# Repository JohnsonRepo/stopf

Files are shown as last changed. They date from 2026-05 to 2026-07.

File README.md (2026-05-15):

# Zigarettenstopfmaschine

DIY vollautomatische Zigarettenstopfmaschine mit zweischichtiger Architektur:
**Raspberry Pi Zero 2 W** (Brain) + **Arduino Nano** (Echtzeitsteuerung).

## Repo-Struktur

Legende: Dateien ohne Marker existieren; **(geplant)** = noch nicht angelegt.

```
stopfmaschine/
├── CLAUDE.md              # Projekt-Kontext für Claude Code
├── README.md              # Dieses File
├── .gitignore
│
├── firmware/
│   └── nano/              # Arduino Nano Firmware
│       ├── src/
│       │   ├── main.cpp           # Einstiegspunkt (Test-Firmware v0.1)
│       │   ├── pins.h             # Pin-Belegung zentral
│       │   └── config.h           # Konstanten (Speeds, Timeouts)
│       │   # (geplant) commands.*, motors.*, sensors.*, statemachine.*
│       └── platformio.ini
│
├── backend/
│   └── pi/                # Raspberry Pi Brain (Python/FastAPI)
│       ├── app/
│       │   ├── __init__.py
│       │   ├── main.py            # FastAPI Entry + Endpoints
│       │   └── nano_client.py     # Serial-Kommunikation
│       │   # (geplant) api/, models/, db/
│       ├── requirements.txt
│       └── # (geplant) tests/
│
├── cad/                   # CAD-Quellen & Fertigungsdateien
│   ├── README.md          # CAD-Doku & Bauteilübersicht
│   ├── source/            # Master-DXFs (Fraens-Originale)
│   ├── drawings/
│   │   └── acryl_parts/   # Laser-Cut-DXFs (4 mm PMMA)
│   ├── reference/
│   │   └── metal_parts/   # Metallteile-Zeichnungen (DXF + PDF)
│   ├── stl/               # 3D-Druck-Dateien (PETG/PLA)
│   └── scad/              # OpenSCAD-Quellen (Platzhalter)
│
├── docs/                  # Schaltpläne & Referenzen
│   ├── wiring.md          # Schaltpläne (Mermaid + ASCII-Detail)
│   ├── pinout.md          # Pin-/Verdrahtungstabellen + Bestelllisten
│   └── protocol.md        # Serial-Protokoll Pi ↔ Nano
│
└── app/                   # Mobile App (Flutter primär) — (geplant)
```

## Schnellstart

### Arduino Nano (PlatformIO empfohlen)

```bash
cd firmware/nano
pio run                    # Kompilieren
pio run -t upload          # Auf Nano flashen
pio device monitor         # Serial Monitor (115200 Baud)
```

### Raspberry Pi Backend

```bash
cd backend/pi
python -m venv .venv
source .venv/bin/activate
pip install -r requirements.txt
uvicorn app.main:app --host 0.0.0.0 --port 8000 --reload
```

API-Docs anschließend unter `http://<pi-ip>:8000/docs`.

## Test-Reihenfolge

Siehe `CLAUDE.md` Abschnitt "Test-Reihenfolge". Wichtigster Hinweis:
**Buck-Konverter VOR Anschluss auf 5,0V justieren** und **A4988 Vref auf 0,7-1,0V einstellen**.

## Sicherheit

⚠️ Diese Maschine arbeitet mit 12V/5A und beweglichen Teilen.
Notaus-Knopf hardware-seitig einbauen (unterbricht 12V direkt).
Watchdog im Nano-Code stoppt alle Motoren bei Pi-Verbindungsverlust > 5s.

## Lizenz / Hinweis

Eigenbau für privaten Gebrauch. Verkauf der Maschine ist nach §30 TabStG verboten.

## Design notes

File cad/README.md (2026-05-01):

# CAD-Verzeichnis

Alle CAD-Quellen, Zeichnungen, 3D-Druck-Dateien und externe Referenzen für die Zigarettenstopfmaschine.

## Verzeichnisstruktur

```
cad/
├── README.md                     # diese Datei
├── source/                       # Master-DXFs (Fraens-Originale, ungesplittet, für Onshape-Import)
├── reference/                    # Externe Referenzen (Fraens-Vorlagen, Metallteile-Zeichnungen)
│   └── metal_parts/              # Einzel-DXFs + PDFs der Metallteile (Pos.63–87)
├── drawings/                     # Fertigungs-fertige Zeichnungen
│   └── acryl_parts/              # Laser-Cut-DXFs für Acryl-Strukturteile (4 mm)
├── stl/                          # STL-Dateien für 3D-Druck (PETG/PLA)
└── scad/                         # OpenSCAD-Quellen für eigene parametrische Anpassungen (leer)
```

**Hinweis:** Aktuell sind keine `.scad`-Dateien vorhanden. Der Ordner ist als Platzhalter angelegt
(via `.gitkeep`), für künftige eigene OpenSCAD-Konstruktionen (z. B. parametrische Halter,
Stopfrohr-Adapter, Magazin-Aufsätze).

**Hinweis Metallteile:** `reference/metal_parts/` ist als Referenz/Bestellunterlage gedacht — das ist,
was an die CNC-/Edelstahl-Werkstatt geht. Falls die Metallteile später als reguläre Eigenfertigung
gelten sollen, kann der Ordner zu `drawings/metal_parts/` verschoben werden.

## Materialien & Fertigungsverfahren

| Kürzel | Bedeutung |
|---|---|
| **PMMA GS 4 mm** | Acrylglas, gegossen, 4 mm Stärke (NICHT extrudiert) — Strukturteile |
| **Edelstahl V2A** | rostfreier Stahl, CNC- oder Laser-geschnitten — Tragteile, Wellen |
| **PETG / PLA** | 3D-Druck-Filament — Halter, Führungen, nicht-tragend |
| **Lasern** | DXF an Laser-Schnitt-Dienstleister (kunststoffplattenonline.de o. ä.) |
| **CNC** | Frästeil oder Edelstahl-Wasserstrahl/Laser |
| **3D-Druck** | Drucken in PETG (mechanische Teile) oder PLA (Prototyp) |

## Bauteilübersicht

| Name | Datei | Material | Fertigung | Status |
|---|---|---|---|---|
| **Acryl-Strukturteile (Master)** | [`source/Acryl cuttings_01.DXF`](source/Acryl%20cuttings_01.DXF) | PMMA GS 4 mm | Lasern | ✅ Master vorhanden |
| **Stopfmaschine Gesamt-Layout** | [`source/Stuffing machine_00.DXF`](source/Stuffing%20machine_00.DXF) | – | Referenz | ✅ |
| **Metallteile-Übersicht (Master)** | [`source/Metal parts.DXF`](source/Metal%20parts.DXF) | Edelstahl V2A / Stahl | CNC / Laser | ✅ Master vorhanden |
| **Grundplatte Pos.75** | [`source/Base plate Pos-75.DXF`](source/Base%20plate%20Pos-75.DXF) | PMMA GS 4 mm | Lasern | ✅ |
| Acryl-Teil Pos.95 | [`drawings/acryl_parts/acryl_teil1.dxf`](drawings/acryl_parts/acryl_teil1.dxf) | PMMA GS 4 mm | Lasern | 🔲 zu bestellen |
| Acryl-Teil Pos.96 | [`drawings/acryl_parts/acryl_teil2.dxf`](drawings/acryl_parts/acryl_teil2.dxf) | PMMA GS 4 mm | Lasern | 🔲 zu bestellen |
| Acryl-Teil Pos.97 | [`drawings/acryl_parts/acryl_teil3.dxf`](drawings/acryl_parts/acryl_teil3.dxf) | PMMA GS 4 mm | Lasern | 🔲 zu bestellen |
| Acryl-Teil Pos.98 | [`drawings/acryl_parts/acryl_teil4.dxf`](drawings/acryl_parts/acryl_teil4.dxf) | PMMA GS 4 mm | Lasern | 🔲 zu bestellen |
| Acryl-Teil Pos.99 | [`drawings/acryl_parts/acryl_teil5.dxf`](drawings/acryl_parts/acryl_teil5.dxf) | PMMA GS 4 mm | Lasern | 🔲 zu bestellen |
| Acryl-Teil Pos.100 | [`drawings/acryl_parts/acryl_teil6.dxf`](drawings/acryl_parts/acryl_teil6.dxf) | PMMA GS 4 mm | Lasern | 🔲 zu bestellen |
| Acryl-Teil Pos.101 | [`drawings/acryl_parts/acryl_teil7.dxf`](drawings/acryl_parts/acryl_teil7.dxf) | PMMA GS 4 mm | Lasern | 🔲 zu bestellen |
| Acryl-Teil Pos.102 | [`drawings/acryl_parts/acryl_teil8.dxf`](drawings/acryl_parts/acryl_teil8.dxf) | PMMA GS 4 mm | Lasern | 🔲 zu bestellen |
| Acryl-Teil Pos.103 | [`drawings/acryl_parts/acryl_teil9.dxf`](drawings/acryl_parts/acryl_teil9.dxf) | PMMA GS 4 mm | Lasern | 🔲 zu bestellen |
| Acryl-Teil Pos.104 | [`drawings/acryl_parts/acryl_teil10.dxf`](drawings/acryl_parts/acryl_teil10.dxf) | PMMA GS 4 mm | Lasern | 🔲 zu bestellen |
| Acryl-Teil Pos.105 | [`drawings/acryl_parts/acryl_teil11.dxf`](drawings/acryl_parts/acryl_teil11.dxf) | PMMA GS 4 mm | Lasern | 🔲 zu bestellen |
| Acryl-Teil Pos.106 | [`drawings/acryl_parts/acryl_teil12.dxf`](drawings/acryl_parts/acryl_teil12.dxf) | PMMA GS 4 mm | Lasern | 🔲 zu bestellen |
| Acryl-Teil Pos.107 | [`drawings/acryl_parts/acryl_teil13.dxf`](drawings/acryl_parts/acryl_teil13.dxf) | PMMA GS 4 mm | Lasern | 🔲 zu bestellen |
| Acryl-Teil Pos.108 | [`drawings/acryl_parts/acryl_teil14.dxf`](drawings/acryl_parts/acryl_teil14.dxf) | PMMA GS 4 mm | Lasern | 🔲 zu bestellen |
| Acryl-Sammelblatt 1 | [`drawings/acryl_parts/acryl1.dxf`](drawings/acryl_parts/acryl1.dxf) | PMMA GS 4 mm | Lasern | ✅ alternative Bestellvorlage |
| Acryl-Sammelblatt 2 | [`drawings/acryl_parts/acryl2.dxf`](drawings/acryl_parts/acryl2.dxf) | PMMA GS 4 mm | Lasern | ✅ alternative Bestellvorlage |
| Metallteile Pos.63–87 (split) | [`reference/metal_parts/`](reference/metal_parts/) | Edelstahl V2A / Stahl | CNC / Laser | 🔲 Werkstatt-Anfrage offen |
| 3D-Druck-Teile (alle) | [`stl/`](stl/) | PETG / PLA | 3D-Druck | 🔄 teilweise gedruckt |

### Status-Legende

- ✅ vorhanden / fertig / verfügbar
- 🔄 in Arbeit / teilweise erledigt
- 🔲 offen / noch zu erledigen
- ❌ verworfen / nicht relevant

## Workflow

1. **Onshape-Anpassungen** → eigene Änderungen parametrisch (Variables für Kernmaße, siehe `CLAUDE.md`).
2. **Export** → DXF in `source/` (Master) bzw. `drawings/acryl_parts/` (Fertigungsstand).
3. **Lasern** → DXF aus `drawings/acryl_parts/` an Dienstleister
   (kunststoffplattenonline.de, S-Polytec.de, Acrylglasplattenshop.de, Plattenzuschnitt24.de).
4. **3D-Druck** → STL aus `stl/` in den Slicer; Empfehlung PETG für mechanische Teile.
5. **Metallteile** → DXF + PDF aus `reference/metal_parts/` an die Edelstahl-Werkstatt.

## Reihenfolge der Eigen-Konstruktion (laut CLAUDE.md)

1. Stopfrohr-Halter + Pusher-Führung
2. Trommelmagazin
3. Tabakmagazin / Gehäuse

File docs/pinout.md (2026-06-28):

# Pinout & Verdrahtungstabelle

Vollständige Belegung aller Pins mit Kabelfarben und Zielbauteil.
Quelle der Pin-Nummern: [`firmware/nano/src/pins.h`](../firmware/nano/src/pins.h).

---

## Arduino Nano (final)

### Digitale Pins

| Pin | `pins.h`-Konstante | Funktion | Ziel | Kabelfarbe (Vorschlag) | Anmerkung |
|---|---|---|---|---|---|
| D2 | `PIN_STEPPER_STEP` | Step-Impuls | A4988 STEP | gelb | jeder steigende Flanke = 1 Step |
| D3 | `PIN_STEPPER_DIR` | Richtung | A4988 DIR | grün | HIGH/LOW = Drehrichtung |
| D4 | `PIN_STEPPER_EN` | Enable | A4988 EN | weiß | **LOW = Treiber aktiv** (invertiert!) |
| D5 | `PIN_PRESS_ENA` | Presse Drehzahl | L298N ENA | gelb | **PWM** Timer0 (Servo-unabhängig) |
| D6 | `PIN_PUSHER_ENB` | Pusher Drehzahl | L298N ENB | grün | **PWM** Timer0 (Servo-unabhängig) |
| D7 | `PIN_PRESS_IN1` | Presse Richtung A | L298N IN1 | orange | digital |
| D8 | `PIN_PRESS_IN2` | Presse Richtung B | L298N IN2 | rot | digital |
| D9 | `PIN_PUSHER_IN3` | Pusher Richtung A | L298N IN3 | violett | digital (Servo killt hier nur PWM) |
| D10 | `PIN_PUSHER_IN4` | Pusher Richtung B | L298N IN4 | blau | digital |
| D11 | `PIN_SERVO` | Servo-Signal Hülsen-Schieber | SG90 (orange Litze) | orange | **PWM** (Servo-Library) |
| D12 | `PIN_HOPPER_MOTOR` | Hülsenmagazin-Motor | MOSFET-Gate (2N7000 / IRLZ44N) | grau | digital ON/OFF (5 V, ~40 mA Last) |
| D13 | `PIN_SOLENOID_2` | Hubmagnet #2 (Top-Druck) | MOSFET-Gate (IRLZ44N) | weiß | digital ON/OFF, Heschen HS-0530B (12 V) |

### Analoge Pins (nutzbar als digital, hier teils analog)

| Pin | `pins.h`-Konstante | Funktion | Ziel | Verdrahtung | Anmerkung |
|---|---|---|---|---|---|
| A0 | `PIN_INIT_PRESS` | Initiator Press | LJ8A3-2-Z/BX (schwarz) | über 10 k + 7,5 k Spannungsteiler | active LOW |
| A1 | `PIN_INIT_PUSH_FRONT` | Initiator Pusher vorne | LJ8A3-2-Z/BX (schwarz) | über 10 k + 7,5 k | active LOW |
| A2 | `PIN_INIT_PUSH_REAR` | Initiator Pusher hinten | LJ8A3-2-Z/BX (schwarz) | über 10 k + 7,5 k | active LOW |
| A3 | – | **frei** (Reserve) | – | – | z. B. zukünftige Sensoren oder I²C-Display |
| A4 | `PIN_SOLENOID_1` | Hubmagnet #1 (Front-Knock) | MOSFET-Gate (IRLZ44N) | digital ON/OFF, Heschen HS-0530B (12 V) |
| A5 | `PIN_MAGAZIN_SENSOR` | Magazin-Gabellichtschranke | Oniissy / Standard-Opto | direkt 5 V-Logik, kein Spannungsteiler |

### Versorgungs-Pins

| Pin | Verbindung | Anmerkung |
|---|---|---|
| **VIN** | – nicht verwenden | Nano wird über USB vom Pi versorgt |
| **5V** | optional kleine Verbraucher (Start-Taster braucht NICHT, Buck-Out hat eigene 5 V) | max. 500 mA aus dem Nano-Regler |
| **3V3** | – nicht verwenden | für 3,3 V-Sensoren reserviert |
| **GND** (mehrfach) | **Sternpunkt am Netzteil** | 1× direkt zum Power-GND, 1× zum Pi |

---

## L298N Standard-Modul (Doppel-DC-Motortreiber, mit Kühlkörper)

> Großes Modul mit Schraubklemmen und ENA/ENB. Drehzahl-Regelung über separate
> Enable-Pins, funktioniert in **beide** Richtungen.

| L298N-Pin | Verbindung | Anmerkung |
|---|---|---|
| V_S (12 V) | 12 V Netzteil + 470 µF Elko (**Schraubklemme**) | Motor-Versorgung |
| GND | GND-Sternpunkt (**Schraubklemme**) | |
| +5 V | – nicht abgreifen für Pi/Servo | Jumper "5V_EN" stecken lassen wenn V_S = 12 V |
| ENA | Nano **D5 (PWM)** | Presse Drehzahl — Timer0, Servo-unabhängig |
| ENB | Nano **D6 (PWM)** | Pusher Drehzahl — Timer0, Servo-unabhängig |
| IN1 | Nano D7 | Presse Richtung A |
| IN2 | Nano D8 | Presse Richtung B |
| IN3 | Nano D9 | Pusher Richtung A |
| IN4 | Nano D10 | Pusher Richtung B |
| OUT1/OUT2 | DC-Motor Presse (**Schraubklemme**) | Polarität egal, ggf. tauschen für Drehrichtung |
| OUT3/OUT4 | DC-Motor Pusher (**Schraubklemme**) | dito |

> ⚠️ **Timer-Konflikt beachten:** `Servo.h` belegt auf dem ATmega328 Timer1 und
> deaktiviert PWM auf D9/D10. ENA/ENB **müssen** deshalb auf D5/D6 (Timer0).
> Die IN-Pins sind reine Richtungs-Logik → D7–D10 unproblematisch (digital).

### Wahrheitstabelle

| INx | INy | ENx (PWM) | Verhalten |
|---|---|---|---|
| HIGH | LOW | > 0 | Motor vorwärts (`fwd`) mit Drehzahl |
| LOW | HIGH | > 0 | Motor rückwärts (`rev`) mit Drehzahl |
| LOW | LOW | beliebig | Motor frei (Coast) |
| HIGH | HIGH | beliebig | Motor gebremst (Brake) |
| beliebig | beliebig | 0 | Motor aus (PWM-Stop) |

> **Vorteil ggü. Mini-Modul:** echte Drehzahl-Regelung in beide Richtungen,
> dicke Litze passt in die Schraubklemmen, Coast (Freilauf) möglich,
> besserer Kühlkörper.

---

## A4988 Schrittmotor-Treiber

| A4988-Pin | Verbindung | Anmerkung |
|---|---|---|
| V_MOT | 12 V + 100 µF Elko | **Pflicht!** Elko < 5 cm vom IC |
| GND (Motor) | GND-Sternpunkt | |
| V_DD | 5 V (vom Nano oder Buck) | Logik-Versorgung |
| GND (Logik) | GND-Sternpunkt | |
| STEP | Nano D2 | |
| DIR | Nano D3 | |
| EN | Nano D4 | LOW = aktiv |
| RESET | mit SLEEP brücken | beide HIGH = Treiber an |
| SLEEP | mit RESET brücken | |
| MS1/MS2/MS3 | offen lassen | Vollschritt; für Microstepping nach Bedarf |
| 1A / 1B | NEMA 17 Spule A | (meist schwarz/grün) |
| 2A / 2B | NEMA 17 Spule B | (meist rot/blau) |
| **Vref-Poti** | mit Multimeter messen | **0,7 ... 1,0 V** vor erstem Anlauf |

---

## NEMA 17 Schrittmotor

Standard-Belegung (variiert pro Hersteller — mit Multimeter durchklingeln!):

| Litzenfarbe (typisch) | Spule | Anschluss |
|---|---|---|
| schwarz | A | A4988 1A |
| grün | A | A4988 1B |
| rot | B | A4988 2A |
| blau | B | A4988 2B |

---

## SG90 Servo (Hülsen-Schieber — einziger Servo)

Im finalen Aufbau gibt es **nur einen Servo** (für das Aufschieben der Hülse).
Die Tabak-Dosierung läuft komplett über 2 Solenoide ohne Servo.

| Litzenfarbe | Funktion | Anschluss |
|---|---|---|
| rot | VCC 5 V | Buck-Out + 470 µF Elko lokal am Servo |
| braun / schwarz | GND | GND-Sternpunkt |
| orange / gelb | Signal (PWM) | Nano **D11** |

---

## Hubmagnete Heschen HS-0530B (2 Stück, Tabak-Dosierung)

12V Push/Pull-Solenoid, ~5 mm Hub, ~3–5 N Zugkraft, ~0,5 A nominal (Halte­strom
bei aktivem Coil ~1 A), ~14×30 mm. Intermittierender Betrieb (kurze Pulse
50–150 ms), nicht für Dauer-ON ausgelegt.

| Litze | Funktion | Anschluss |
|---|---|---|
| Solenoid #1 (Front-Knock) | beide Anschlüsse | über MOSFET-Treiber an Nano A4 |
| Solenoid #2 (Top-Druck) | beide Anschlüsse | über MOSFET-Treiber an Nano D13 |

Steuerung pro Solenoid via **Logic-Level-MOSFET** (z. B. IRLZ44N):

| Bauteil | Anschluss |
|---|---|
| Solenoid + | 12 V-Bus (über F4 = 1 A T) |
| Solenoid − | Drain des MOSFETs |
| 1N5819 Flyback | Kathode an +12 V, Anode an Drain (parallel zum Solenoid) |
| MOSFET Source | GND-Sternpunkt |
| MOSFET Gate | über 100 Ω Series an Nano-Pin (A4 oder D13) |

> **Warum nicht L298N-Mini?** Wäre theoretisch ein 2-Kanal-Treiber für beide
> Solenoide. **Aber:** Halte­strom 1 A × 2,5 V L298N-Drop = 2,5 W pro Kanal,
> bei beiden aktiv 5 W → das Mini-Modul ohne Kühlkörper überhitzt. MOSFET hat
> < 20 mV Drop → kalt.

> **Polung Solenoid:** DC-Solenoide haben keine elektrische Polarität, aber
> konsistente Anschluss-Konvention vereinfacht Wartung.

> **Flyback-Diode Pflicht** (nicht optional wie bei L298N) — beim Abschalten
> erzeugt die Solenoid-Spule eine hohe Back-EMF-Spitze, die den MOSFET ohne
> Schutz beschädigt.

---

## Hülsenmagazin-Motor (1 Stück, 5 V Vibrationsmotor)

Kleiner DC-Motor zum Vorrücken/Rütteln der Hülsen im Magazin. ~40 mA bei 5 V,
nur on/off (Drehzahl-Regelung nicht nötig).

| Bauteil | Anschluss |
|---|---|
| Motor + | 5 V-Bus (vom Buck-Out, nicht vom Nano-5V-Pin) |
| Motor − | Drain des MOSFETs |
| 1N4148 Flyback | Kathode an +5 V, Anode an Drain (parallel zum Motor) |
| MOSFET Source | GND-Sternpunkt |
| MOSFET Gate | über 1 kΩ Series an Nano D12 |

> **MOSFET-Wahl:** 2N7000 (TO-92, ~10 ct) ist optimal für 40 mA. IRLZ44N geht
> auch (overkill aber konsistent mit Solenoid-Treibern).

> **Warum 1N4148 statt 1N5819?** Bei 40 mA reicht die 200 mA-Dauerlast-
> Spec der 1N4148 dicke. 1N5819 wäre overkill und die hast du eh für die
> Solenoide.

> **Nicht direkt vom Nano-Pin treiben:** Nano-Pin verträgt max 40 mA — exakt am
> Limit, plus Anlaufspitze + Back-EMF → Pin-Schutzdiode wird über Zeit stressed.
> MOSFET ist die sichere Lösung.

---

## Start-Taster — entfällt

Manueller Hardware-Start ist nicht vorgesehen. Die Maschine wird **komplett
remote** über den Raspberry Pi gesteuert (HTTP-API, später BLE). Pin D12 ist
für den Hülsenmagazin-Motor umgewidmet.

---

## Initiatoren LJ8A3-2-Z/BX oder LJ12A3-4-Z/BX (3 Stück)

| Litzenfarbe | Funktion | Anschluss |
|---|---|---|
| braun | +12 V | 12 V Bus |
| blau | GND | GND-Sternpunkt |
| schwarz | Signal (NPN, 12 V active LOW) | Spannungsteiler 10 k + 7,5 k → A0 / A1 / A2 |

> **LJ8 vs. LJ12:** elektrisch identisch (NPN, active LOW, gleicher Spannungsteiler,
> gleicher Code). Unterschied nur mechanisch: LJ8 = M8/2 mm Schaltabstand,
> LJ12 = M12/4 mm (größere Bohrung, Target ≥ 12×12 mm). Beide verwendbar.

---

## Raspberry Pi Zero 2 W (Brain)

| Pi-Pin | Funktion | Anschluss |
|---|---|---|
| Pin 2 (5 V) | Versorgung **rein** | Buck-Out 5 V (≥ 3 A) |
| Pin 6 (GND) | GND | GND-Sternpunkt |
| – | USB-A oder Micro-USB-OTG | → Arduino Nano (Daten + 5 V Versorgung des Nano) |
| Pin 8 (TX) / Pin 10 (RX) | optional: UART zum Nano | falls USB nicht genutzt — mit Pegelwandler! |

> **Pi NICHT über Micro-USB-Power speisen** (Polyfuse begrenzt → Brownout unter Last).
> 5 V immer über GPIO Pin 2 einspeisen, Buck vorher auf 5,0 V justieren.

---

## ESP-WROOM-32 (Übergangslösung, parallel dokumentiert)

> Solange der Buck-Konverter noch nicht da ist, kann ein ESP32 als Single-Board-
> Controller alle Funktionen übernehmen. Pin-Mapping ist bewusst anders, weil
> manche ESP32-Pins Boot-Strapping-Pins oder input-only sind.

| Funktion | ESP32 GPIO | Anmerkung |
|---|---|---|
| A4988 STEP | GPIO 25 | |
| A4988 DIR | GPIO 26 | |
| A4988 EN | GPIO 27 | |
| L298N IN1 | GPIO 14 | |
| L298N IN2 | GPIO 12 | ⚠️ Boot-Strapping |
| L298N IN3 | GPIO 13 | |
| L298N IN4 | GPIO 32 | |
| L298N ENA | GPIO 33 | PWM |
| L298N ENB | GPIO 4 | PWM |
| Servo | GPIO 19 | PWM (LEDC-Kanal) |
| (Start-Taster) | – | **entfällt — Steuerung remote über Pi** |
| Initiator Press | GPIO 34 | ⚠️ input-only, kein Pull-Up |
| Initiator PushFront | GPIO 35 | ⚠️ input-only |
| Initiator PushRear | GPIO 36 | ⚠️ input-only |
| Magazin-Sensor | GPIO 39 | ⚠️ input-only |

⚠️ **Spannungsteiler für ESP32:** 10 kΩ + **3,9 kΩ** (nicht 7,5 kΩ wie beim Nano).
   U_out = 12 V · 3,9/13,9 ≈ 3,37 V — innerhalb 3,3 V-Toleranz.

⚠️ **Boot-Strapping-Pins** (GPIO 0, 2, 5, 12, 15) nur mit Bedacht nutzen — falsche
   Pegel beim Reset verhindern den Boot.

---

## Elektrolytkondensatoren (Bestellliste)

Zentrale Pufferkondensatoren — alle 105 °C, radial THT.

| Position | Kapazität | Spannung | Typ | Anzahl | Begründung |
|---|---|---|---|---|---|
| **A4988 V_MOT** | ≥ 100 µF (220 µF besser) | **≥ 25 V** | **Low ESR** Pflicht | 1× | Schaltet 500 kHz, Standard-Elkos zu lahm |
| **L298N V_S** | ≥ 470 µF (1000 µF besser) | **≥ 25 V** | Standard reicht | 1× | DC-Motor-Anlaufstrom puffern |
| **Servo VCC** | ≥ 470 µF (bis 2200 µF) | ≥ 10 V (16 V/25 V auch ok) | Standard | 1× | Servo-Anlaufstrom 0,5–1 A |
| **Buck-Ausgang Bulk** (optional) | 470–1000 µF | ≥ 10 V | Standard | 1× | nur falls Pi und Servo räumlich weit auseinander |

> ⚠️ **Niemals 16 V-Elkos im 12 V-Pfad!** Headroom 33 % ist zu knapp gegen
> Spannungsspikes von Motoren — Elko explodiert, Treiber stirbt mit. Mindestens
> 25 V im 12 V-Pfad. Im 5 V-Pfad sind 10 V/16 V/25 V alle okay (alle ≥ 2× U_op).

### Konkret zum Bestellen

| Bauteil | Quelle | Preis |
|---|---|---|
| Panasonic FC 100 µF/35 V (low ESR) | Reichelt: "FC 100/35" | ~0,40 € |
| Panasonic FC 470 µF/35 V (low ESR) | Reichelt: "FC 470/35" | ~0,80 € |
| Standard 470 µF/25 V/105 °C | Reichelt: "RAD 470/25" | ~0,30 € |
| Standard 1000 µF/35 V/105 °C | Reichelt: "RAD 1000/35" | ~0,80 € |

### Optionale Schutzbauteile

| Bauteil | Wert | Anzahl | Position |
|---|---|---|---|
| Schottky-Flyback-Diode | 1N5819 (1 A, 40 V) | 8× (DC-Motoren) + 2× (Solenoide) | 4 pro DC-Motor an L298N-Ausgängen; 2 für die Heschen-Solenoide (Pflicht!) |

### MOSFET-Treiber (Pflicht für Tabak-Solenoide + Hülsenmagazin-Motor)

| Bauteil | Wert | Anzahl | Position |
|---|---|---|---|
| **MOSFET Logic-Level** | IRLZ44N (TO-220, 30A, ~17 mΩ Rds_on) | 3× | je 1 pro Solenoid + 1 für Hopper-Motor (overkill ok) |
| Alternativ Hopper-Motor | 2N7000 oder BS170 (TO-92, klein) | 1× statt IRLZ44N | nur 40 mA — kleiner ist genug |
| Flyback-Diode Hopper | **1N4148** (200 mA, 100 V) | 1× | parallel zum 40-mA-Motor (1N5819 wäre overkill) |
| Gate-Series-Widerstand | 100 Ω (Solenoide) / 1 kΩ (Hopper) | 3× | dämpft Gate-Switching |

Kosten gesamt: ~1,50 € (3× IRLZ44N + 2× 1N5819 + 1× 1N4148 + 3× R).

---

## Litze / Kabel (Bestellliste)

### Querschnitt pro Strecke

| Strecke | Strom (peak) | Querschnitt | AWG | Farbe |
|---|---|---|---|---|
| **PSU 12 V → F1 → Verteiler** | bis 5 A | **1,0 mm²** | AWG 17 | rot |
| **PSU GND → Sternpunkt** | bis 5 A | **1,0 mm²** | AWG 17 | schwarz |
| 12 V → L298N V_S | 3 A peak | 0,75 mm² | AWG 18 | rot |
| 12 V → A4988 V_MOT | 1 A peak | 0,5 mm² | AWG 20 | rot |
| 12 V → Buck-Eingang | 1 A | 0,5 mm² | AWG 20 | rot |
| 12 V → Initiatoren (braun) | 50 mA | 0,25 mm² | AWG 24 | braun |
| Buck 5 V → Pi GPIO 2 | 700 mA | 0,5 mm² ⚠️ kurz halten | AWG 20 | gelb/orange |
| Buck 5 V → Servo VCC | 1 A peak | 0,5 mm² ⚠️ kurz halten | AWG 20 | rot (am Servo) |
| Buck 5 V → A4988 V_DD | 50 mA | 0,25 mm² | AWG 24 | gelb |
| **Motor-Leitungen L298N → DC-Motor** | 1,5 A | 0,5–0,75 mm² | AWG 18–20 | blau / weiß |
| **NEMA 17 → A4988 (4-adrig)** | 1 A pro Phase | 0,5 mm² je Ader | AWG 20 | schwarz/grün/rot/blau |
| Logik-Signale (STEP, DIR, EN, IN1–4) | < 50 mA | 0,14–0,25 mm² | AWG 26–24 | beliebig |
| Servo-Signal (PWM von Nano) | < 20 mA | 0,14 mm² | AWG 26 | orange |
| MOSFET-Gate-Leitungen (Nano → Gate, mit 100Ω/1kΩ Series) | < 1 mA | 0,14 mm² | AWG 26 | grau |
| Initiator-Signal (schwarz) | < 20 mA | 0,25 mm² | AWG 24 | schwarz/grün |
| GND-Rückleitungen | **wie Hinweg!** | gleicher Querschnitt | – | schwarz |

> ★ **GND-Litze immer mindestens so dick wie die +Leitung.**
> Wer hier spart, bekommt Massepotential-Probleme.

### Spannungsabfall-Überlegung

Faustformel: `U_drop = I · ρ · L / A` mit `ρ_Kupfer = 0,017 Ω·mm²/m`

Toleranz:
- **5 V-Schiene**: max. **100 mV** Drop (sonst Pi-Brownout)
- **12 V-Schiene**: max. **500 mV** Drop (sonst spüren's die Treiber)

Beispiele:
| Pfad | I | L | A | U_drop |
|---|---|---|---|---|
| PSU → Verteiler | 5 A | 0,3 m | 1,0 mm² | 25 mV ✅ |
| PSU → Verteiler | 5 A | 0,3 m | 0,5 mm² | 51 mV ⚠️ |
| Buck → Pi | 0,7 A | 0,5 m | 0,5 mm² | 12 mV ✅ |
| Buck → Pi | 0,7 A | 1,0 m | 0,25 mm² | 48 mV ⚠️ |

### Litze vs. Massivdraht

| | **Litze** (stranded) | Massivdraht (solid) |
|---|---|---|
| Mechanik | flexibel, vibrationsfest | bricht bei wiederholtem Biegen |
| WAGO 221 | ✅ direkt | ✅ direkt |
| Schraubklemme | nur mit **Aderendhülse** | ohne Hülse |
| Empfehlung Stopfmaschine | ✅ **Litze** wegen Vibrationen | nur für kurze Drahtbrücken |

### Aderendhülsen — wann nötig?

| Klemmen-Typ | Aderendhülse? |
|---|---|
| WAGO 221 (Hebelklemme) | ❌ NICHT nötig |
| Schraubklemme (z. B. an L298N, A4988) | ✅ **PFLICHT** |
| Lüsterklemme | ✅ Pflicht |
| Crimp-Stecker (Dupont, JST) | — wird direkt vercrimpt |
| Federzugklemme (Phoenix) | ❌ direkt |

Aderendhülsen-Set 0,14–2,5 mm² mit Crimpzange: ~15–25 €
(Amazon "Knipex-Set" oder Generic).

### Wenn du nur EINE Litze kaufst

→ **0,5 mm² (AWG 20) ist der universelle DIY-Kompromiss.**
Geht für alle 5 V-Leitungen, Treiber-Versorgungen, Motoren, Sensor-Stromversorgung.
Reicht **nicht** für die Hauptzuleitung PSU → Verteiler (zu hoher Spannungsabfall bei 5 A).

### Konkretes Bestell-Paket

| Querschnitt | Menge | Farben | Quelle |
|---|---|---|---|
| 1,0 mm² | 1 m rot + 1 m schwarz | – | Reichelt: "LIY 1,00 RT/SW" |
| 0,5 mm² | 2–3 m rot + schwarz + 2 andere | rot/schwarz/blau/gelb | "LIY 0,50 …" |
| 0,25 mm² | je 1 m in 4–6 Farben | gemischt | "LIY 0,25 …" |
| **Set-Alternative** | 5 m × 10 Farben × 0,25 mm² | gemischt | Amazon: "Litze Sortiment 24 AWG 10 Farben" ~12 € |

**Gesamtbudget für komplette Verkabelung: ~15–25 €**

---

## Spannungsteiler für Initiatoren (Bestellliste)

Pro Sensor-Eingang (3× für Press / PushFront / PushRear):

| Bauteil | Wert | Anzahl | Bauform | Anmerkung |
|---|---|---|---|---|
| R1 | 10 kΩ, 5 %, 1/4 W | 3× (+ Reserve) | THT 0207 | Standard-Kohleschicht |
| R2 (Nano) | 7,5 kΩ, 5 %, 1/4 W | 3× | THT 0207 | für 5 V-Logik (Standard) |
| R2 Ersatz #1 | **6,8 kΩ** statt 7,5 kΩ | 3× | THT 0207 | häufiger lagernd, U_out 4,86 V |
| R2 Ersatz #2 | **5,6 kΩ + 2 kΩ in Reihe** | je 3× | THT 0207 | falls 7,5/6,8 fehlen — Reihe addiert zu 7,6 kΩ |
| R2 (ESP32) | 3,9 kΩ, 5 %, 1/4 W | 3× | THT 0207 | für 3,3 V-Logik |
| C (Filter) | 47 nF Keramik | 3× | X7R, 50 V | parallel zu R2, EMV-Filter |

Optionale Pull-up-Bestückung **falls** der Sensor im Leerlauf < 10 V auf Schwarz zeigt:

| Bauteil | Wert | Anzahl | Anmerkung |
|---|---|---|---|
| R_pullup | 4,7 kΩ, 1/4 W | 3× | von "schwarz" nach +12 V, **nur wenn nötig** |

> Vor dem Anschluss am Nano: Test-Checkliste in [`wiring.md` § 3](wiring.md#3-initiator-spannungsteiler-kritisch) durchgehen.

---

## Sicherungen (Bestellliste)

Alle 5×20 mm Schmelzsicherungen (Glas oder Keramik beide ok), in Schraubklemmen-Halter
(z. B. Stelvio Kontek PTF/30 oder beliebiger Würth/Schurter-Halter).

| Position | Wert | Charakteristik | Schützt | Halter-Typ |
|---|---|---|---|---|
| **F1** Hauptsicherung 12 V | 5 A | T (träge) | gesamten 12 V-Bus, Verkabelung | Schraubklemme, Panel-mount |
| **F2** Buck-Eingang | 1 A | T (träge) | Pi + Servo + Nano-Logik | Schraubklemme, inline |
| **F3** Initiator-Schiene | 500 mA | F (flink) | Sensor-Verkabelung | Schraubklemme, inline |

> **Glas oder Keramik — beides ok für 12 V DC.** Beide elektrisch identisch
> (gleicher Wert, gleiche Charakteristik T/F). Glas ist günstiger (~0,30 € vs.
> ~1–2 €), Keramik hat mehr Headroom bei Hochstrom-Fehlern. Für diese Maschine
> Wahl-Sache. Keramik **wird** Pflicht bei AC-Netzseite (vor dem 12 V-Netzteil)
> oder Bleibatterie/LiPo-Versorgung > 100 A Kurzschluss. Details in
> [`wiring.md` § 1](wiring.md#1-stromversorgung-power-distribution).

> **Reserve mitbestellen:** je Wert mind. 5 Stück, sind günstig (~0,30 €/Stück).

---

## GND-Sternpunkt (★ kritisch ★)

Alle GNDs an **einem Punkt** zusammenführen, am besten direkt an der GND-Klemme
des 12 V-Netzteils. Sterntopologie verhindert Masseschleifen und Spannungs-
abfall-Probleme bei pulsenden Lasten (Schrittmotor, DC-Motor).

```
                  Netzteil GND (Sternpunkt)
                         │
     ┌──────┬──────┬─────┼──────┬───────┬───────┐
     │      │      │     │      │       │       │
   Pi GND  Nano  Buck  L298N  A4988  Servo   Initiatoren
                  GND   GND    GND    GND      (alle 3, blau)
```

---

## Verwandte Dokumente

- [`wiring.md`](wiring.md) — Schaltpläne und Spannungsteiler-Details
- [`protocol.md`](protocol.md) — Serial-Befehle Pi ↔ Nano
- [`../firmware/nano/src/pins.h`](../firmware/nano/src/pins.h) — Pin-Defines im Code
- [`../firmware/nano/src/config.h`](../firmware/nano/src/config.h) — Konstanten (Speeds, Timeouts)

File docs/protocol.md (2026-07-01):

# Serial-Protokoll Pi ↔ Nano

Textbasiertes Protokoll über USB-Serial, **115200 Baud, 8N1**.
Ein Befehl pro Zeile, mit `\n` (LF) terminiert. Antworten zeilenweise.

> **Implementiert in:** [`../firmware/nano/src/main.cpp`](../firmware/nano/src/main.cpp)
> **Konsumiert von:** [`../backend/pi/app/nano_client.py`](../backend/pi/app/nano_client.py)

---

## 1. Designprinzipien

| Regel | Begründung |
|---|---|
| **Ein Befehl pro Zeile**, terminiert mit `\n` | trivial zu parsen, in jedem Terminal-Tool testbar |
| **Antwort beginnt mit Schlüsselwort** (`ok`, `err`, `status`, `warn`, `pong`) | Pi kann auf Erfolg/Fehler matchen ohne JSON-Parser |
| **Befehle kleingeschrieben**, Antworten kleingeschrieben | konsistent, einfacher zu vergleichen |
| **Nano hat keine eigene Logik** — nur Befehlsausführung | jede Zustandsmaschine läuft auf dem Pi |
| **Watchdog**: 5 s ohne Befehl → alle Motoren AUS | Sicherheit bei Pi-Ausfall |
| **Synchron**: jeder Befehl bekommt genau eine Antwortzeile | (Ausnahmen: `status`, `warn …`) |

---

## 2. Befehlsübersicht

### Konnektivität

| Befehl | Antwort | Beschreibung |
|---|---|---|
| `ping` | `pong` | Verbindungstest. Pi sollte das nach Connect zuerst senden. |
| `help` | mehrzeilige Hilfe | Liste aller Befehle (für manuelles Debuggen) |
| `status` | `status press=B push_front=B push_rear=B magazin=B magazin_raw=B sol1=B sol2=B hopper=B stepper_pos=N` | Sensor-Snapshot (`B` = `0`/`1`, `N` = signed long) |

### Schrittmotor (Trommelmagazin-Drehung)

| Befehl | Antwort | Beschreibung |
|---|---|---|
| `stepper <N>` | `ok stepper <N>` | Bewegt Schrittmotor um N Steps. Negativ = rückwärts. |

Beispiele:

```
stepper 400      → 400 Steps vorwärts (Tabakdosis lt. Default)
stepper -200     → 200 Steps rückwärts
stepper 0        → no-op (aber Watchdog wird "gefüttert")
```

### DC-Motoren (Presse + Pusher)

| Befehl | Antwort | Beschreibung |
|---|---|---|
| `press fwd` | `ok press fwd` | Presse vorwärts mit `PRESS_SPEED_DEFAULT` (PWM via ENA) |
| `press rev` | `ok press rev` | Presse rückwärts, ebenfalls drehzahlgeregelt (ENA-PWM) |
| `press stop` | `ok press stop` | Presse aus |
| `pusher fwd` | `ok pusher fwd` | Pusher vorwärts mit `PUSHER_SPEED_DEFAULT` (PWM via ENB) |
| `pusher rev` | `ok pusher rev` | Pusher rückwärts, ebenfalls drehzahlgeregelt (ENB-PWM) |
| `pusher stop` | `ok pusher stop` | Pusher aus |

> Mit dem großen L298N (ENA/ENB) ist die Drehzahl in **beide** Richtungen
> geregelt — anders als beim Mini-Modul, wo Rückwärts fix volle Drehzahl war.

### Servo (Hülsen-Schieber)

| Befehl | Antwort | Beschreibung |
|---|---|---|
| `servo <0..180>` | `ok servo <angle>` | Fährt Servo auf Winkel (geclamped 0–180). |

Wichtige Positionen (siehe `config.h`):
- `servo 5` → Hülse fertig aufgeschoben (`SERVO_POS_HOME`)
- `servo 85` → Hülse aufnehmen (`SERVO_POS_LOAD`)

### Tabak-Dosierung (Tilt-Servo + 2 Solenoide via MOSFETs)

| Befehl | Antwort | Beschreibung |
|---|---|---|
| `solenoid 1 pulse <ms>` | `ok sol1 pulse <ms>` | Hubmagnet #1 (Front-Knock) für ms an, dann aus (max 1000 ms) |
| `solenoid 1 off` | `ok sol1 off` | Hubmagnet #1 aus |
| `solenoid 1 on` | `err on_disabled sol1` | **Dauer-ON deaktiviert** (Magnet-Schutz, ab v0.3.1) |
| `solenoid 2 off\|pulse <ms>` | wie #1 | Hubmagnet #2 (Top-Druck) |
| `knock` | `ok knock start cycles=8` ... `ok knock done` | Komplette Knock-Sequenz mit Default-Cycles (8) |
| `knock <n>` | wie oben | mit `n` statt Default |

Konstanten (in `config.h`):
- `KNOCK_PULSE_ON_MS = 80`, `KNOCK_PULSE_OFF_MS = 120`, `KNOCK_CYCLES_DEFAULT = 8`
- `SOLENOID_PULSE_MAX_MS = 1000` (max Einzelpuls — Heschen nicht für Dauer-ON)

> **Kein Tabak-Servo** — Knock-Sequenz pulst nur die zwei Solenoide synchron.
> Der einzige Servo im System ist der Hülsen-Schieber (D11).

### Hülsenmagazin-Motor (kleiner 5 V DC via MOSFET)

| Befehl | Antwort | Beschreibung |
|---|---|---|
| `hopper on` | `ok hopper on` | Motor an (bis `off`, `stop` oder Watchdog) |
| `hopper off` | `ok hopper off` | Motor aus |
| `hopper run <ms>` | `ok hopper run <ms>` | Motor für ms an, dann aus (max 4000 ms wegen Watchdog) |

Konstante: `HOPPER_DEFAULT_MS = 1500` (Default wenn `run 0`).

### Sicherheit

| Befehl | Antwort | Beschreibung |
|---|---|---|
| `stop` | `ok stop` | Sofort-Stopp **aller** Aktoren (DC-Motoren, Stepper, Solenoide, Hopper). |

---

## 3. Antwort-Schemata

```
ok <verb> <args...>           # Erfolg, optional mit Echo der Argumente
err unknown_command:<text>    # Befehl nicht erkannt (Echo zur Diagnose)
err <reason>                  # Anderer Fehler (z. B. ERROR pusher_stuck — geplant)
warn watchdog_timeout motors_off
                              # Spontane Warnung vom Nano (KEIN Antwort-Satz)
status press=<0|1> push_front=<0|1> push_rear=<0|1> magazin=<0|1>
       magazin_raw=<0|1> sol1=<0|1> sol2=<0|1> hopper=<0|1> stepper_pos=<N>
                              # Antwort auf "status"
pong                          # Antwort auf "ping"
ready firmware=<version>      # Bei Boot, einmalig
```

> **Spontane `warn`-Zeilen** (z. B. Watchdog) können jederzeit auftauchen. Der Pi-
> Reader muss damit umgehen, dass nach einem Befehl ggf. mehr als eine Zeile kommt.

---

## 4. Sequenzbeispiel: eine Zigarette stopfen

Nano-Antworten **kursiv**.

```
Pi → ping
Pi ← pong

Pi → status
Pi ← status press=0 push_front=0 push_rear=1 stepper_pos=0

# 1) Tabak dosieren
Pi → stepper 400
Pi ← ok stepper 400
   (Pi wartet ~500 ms — Stepper läuft non-blocking auf dem Nano weiter)

# 2) Pressen, bis Initiator Press auslöst
Pi → press fwd
Pi ← ok press fwd
Pi → status                    (mehrfach gepollt im 50-ms-Takt)
Pi ← status press=1 push_front=0 push_rear=1 stepper_pos=400
Pi → press stop
Pi ← ok press stop

# 3) Hülse aufsetzen
Pi → servo 85
Pi ← ok servo 85
Pi → servo 5
Pi ← ok servo 5

# 4) Stopfen, bis Initiator PushFront auslöst
Pi → pusher fwd
Pi ← ok pusher fwd
Pi → status                    (Polling)
Pi ← status press=0 push_front=1 push_rear=0 stepper_pos=400
Pi → pusher stop
Pi ← ok pusher stop

# 5) Pusher zurück bis Initiator PushRear
Pi → pusher rev
Pi ← ok pusher rev
Pi → status                    (Polling)
Pi ← status press=0 push_front=0 push_rear=1 stepper_pos=400
Pi → pusher stop
Pi ← ok pusher stop
```

---

## 5. Watchdog-Verhalten

```
T=0      letzter Befehl empfangen → lastCommandMs = 0
T=4,9 s  noch nichts geschehen → alles weiter
T=5,0 s  WATCHDOG_TIMEOUT_MS überschritten
         → allMotorsOff()  (inkl. Solenoide + Hopper-Motor!)
         Nano → Pi: warn watchdog_timeout motors_off
T=5,1 s  Pi sendet: ping
         Nano → Pi: pong
         (Watchdog wieder aktiv, nächste 5 s bewacht)
```

> Der Pi sollte mindestens alle **2 s** ein `ping` oder `status` senden, um den
> Watchdog zu füttern, auch wenn gerade keine aktive Sequenz läuft.

---

## 6. Geplante Erweiterungen (noch nicht implementiert)

Folgende Befehle stehen in [`../CLAUDE.md`](../CLAUDE.md) und sind **geplant**:

| Befehl | Zweck | Status |
|---|---|---|
| `home` | Referenzfahrt Trommel via Magazin-Lichtschranke | 🔲 |
| `stuff [<n>]` | komplette Stopfsequenz (1 oder n Zigaretten) | 🔲 wenn `statemachine.cpp/.h` existiert |
| `set_press_time <ms>` | Presszeit zur Laufzeit setzen | 🔲 |
| `set_push_speed <pwm>` | Pusher-Geschwindigkeit setzen | 🔲 |
| `set_knock_cycles <n>` | Anzahl Knock-Wiederholungen pro Dose ändern | 🔲 |
| `abort` | sequenz sauber abbrechen, alle Aktoren in safe state | 🔲 (entspricht aktuell `stop`) |

Implementierte Tabak/Hopper-Befehle (`solenoid 1|2`, `knock`, `hopper`)
siehe Sektion 2 oben — Bestandteil von Firmware v0.2.

Bis diese existieren, baut der Pi die Sequenz aus den **bestehenden** Befehlen
(`stepper`, `press fwd/stop`, `servo`, `pusher fwd/rev/stop`) zusammen.

---

## 7. Manuelles Testen

### Mit `pio device monitor` (Arduino IDE / PlatformIO)

```bash
cd firmware/nano
pio device monitor      # öffnet Serial Monitor mit 115200 Baud
> ping
< pong
> help
< === Stopfmaschine Test-Firmware ===
< ...
> stepper 200
< ok stepper 200
```

### Mit `screen` oder `minicom` (Linux/macOS)

```bash
screen /dev/ttyACM0 115200       # ggf. /dev/ttyUSB0
# Beenden: Ctrl-A, dann k, dann y
```

### Aus Python testen

```python
import serial
nano = serial.Serial("/dev/ttyACM0", 115200, timeout=1)
nano.write(b"ping\n")
print(nano.readline())   # b'pong\n'
```

---

## 8. Fehlerbehandlung im Pi

Empfohlene Pattern für [`nano_client.py`](../backend/pi/app/nano_client.py):

```python
async def send(self, cmd: str, timeout: float = 1.0) -> str:
    self._serial.write((cmd + "\n").encode())
    deadline = time.monotonic() + timeout
    while time.monotonic() < deadline:
        line = (await self._readline()).decode().strip()
        if not line:
            continue
        if line.startswith("warn "):
            log.warning("nano: %s", line)        # nicht als Antwort werten
            continue
        return line                              # erste echte Antwort
    raise TimeoutError(f"no reply for {cmd!r}")
```

Empfehlungen:

- **`warn`-Zeilen ignorieren** (oder ans Logging weiterleiten), nicht als Antwort werten.
- Bei `err unknown_command:…` ist der Befehl falsch geschrieben — programmatischer Fehler, nicht recoverable.
- Bei Timeout: erst `ping` versuchen, dann ggf. Serial neu öffnen.

---

## Verwandte Dokumente

- [`wiring.md`](wiring.md) — Schaltpläne
- [`pinout.md`](pinout.md) — Pin-Belegung
- [`../firmware/nano/src/main.cpp`](../firmware/nano/src/main.cpp) — Befehlsparser
- [`../backend/pi/app/nano_client.py`](../backend/pi/app/nano_client.py) — Pi-seitiger Serial-Client

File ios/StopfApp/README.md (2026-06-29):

# Stopfmaschine — iOS App

SwiftUI-App zur Fernsteuerung der Stopfmaschine über das Pi-Backend (FastAPI v0.3.0).

- **Min-Target:** iOS 17.0
- **Architektur:** SwiftUI + `@Observable` (Observation framework), async/await
- **Keine 3rd-Party-Dependencies** — nur Foundation, SwiftUI, Network

## Verbindung

Die App spricht ausschließlich mit dem Pi (nicht direkt mit dem Nano):

```
iPhone  ──HTTP/JSON + WebSocket──►  Pi (stopf.local:8000)  ──USB-Serial──►  Nano
```

Discovery via Bonjour (`_stopf._tcp`), mit manueller Host-Eingabe als Fallback.

---

## Xcode-Projekt anlegen (einmalig)

Ich kann die `.xcodeproj`-Datei nicht zuverlässig per Hand erzeugen — die legst du
in 6 Klicks selbst an, danach werden die mitgelieferten Swift-Files importiert.

1. **Xcode öffnen** → *File ▸ New ▸ Project…*
2. *iOS ▸ App* wählen → **Next**
3. Felder:
   - Product Name: `StopfApp`
   - Team: dein Apple-ID-"Personal Team" (kostenlos, sideload-tauglich)
   - Organization Identifier: z.B. `com.deinname`
   - Interface: **SwiftUI**
   - Language: **Swift**
   - Storage: **None** (kein Core Data)
4. Als Speicherort **diesen Ordner** (`ios/StopfApp/`) wählen.
   ⚠️ Xcode legt `StopfApp/StopfApp/` an — genau dort liegen schon die Sources.
   Wenn Xcode fragt ob es überschreiben soll: die von Xcode generierte
   `StopfApp.swift` und `ContentView.swift` **löschen** und stattdessen die
   mitgelieferten Files behalten (siehe unten).
5. Projekt-Settings ▸ *General* ▸ **Minimum Deployments = iOS 17.0**.
6. Die mitgelieferten Ordner `Models/`, `Services/`, `Views/` per Drag&Drop in den
   Xcode-Navigator ziehen (falls nicht automatisch erkannt). "Create groups" wählen.

### Auto-generierte Files ersetzen
Xcode erzeugt beim Anlegen `StopfAppApp.swift` (oder `StopfApp.swift`) und
`ContentView.swift`. Beide löschen — dieses Repo bringt `StopfApp.swift` (App-Entry)
und `Views/RootView.swift` mit.

---

## Info.plist-Einträge (Pflicht für Bonjour + HTTP im LAN)

Ab Xcode 13 gibt es keine sichtbare `Info.plist` mehr by default. Trage die Keys
unter *Target ▸ Info ▸ Custom iOS Target Properties* ein, oder füge die
mitgelieferte `Info-additions.plist`-Snippets manuell hinzu:

| Key | Typ | Wert |
|---|---|---|
| `NSLocalNetworkUsageDescription` | String | `Die App sucht die Stopfmaschine im lokalen Netzwerk.` |
| `NSBonjourServices` | Array | Item 0 (String): `_stopf._tcp` |
| `NSAppTransportSecurity` | Dict | siehe unten |

**ATS (HTTP statt HTTPS im lokalen Netz erlauben):**
```
NSAppTransportSecurity (Dictionary)
└─ NSAllowsLocalNetworking (Boolean) = YES
```
`NSAllowsLocalNetworking` erlaubt Klartext-HTTP nur zu `.local`-Hostnamen und
privaten IP-Bereichen — genau unser Fall. Kein generelles
`NSAllowsArbitraryLoads` nötig.

---

## Build & Run

1. iPhone per USB anstecken (oder Simulator — Bonjour funktioniert im Sim nur
   eingeschränkt, manuelle Eingabe `Mac-IP:8000` nutzen wenn das Backend auf dem
   Mac läuft).
2. In Xcode oben das Zielgerät wählen → **⌘R**.
3. Beim ersten Start: iOS fragt nach *Lokales Netzwerk*-Berechtigung → **Erlauben**.
4. Settings-Tab → "Suchen" → Pi sollte als `Stopfmaschine on …` auftauchen.

---

## Projektstruktur

```
StopfApp/
├── StopfApp.swift            App-Entry (@main)
├── Models/
│   ├── MachineStatus.swift   Status-Snapshot vom Nano
│   └── Params.swift          18 EEPROM-Parameter + UI-Metadaten
├── Services/
│   ├── AppState.swift        zentrale @Observable-Config + Clients
│   ├── APIClient.swift       REST (async/await)
│   ├── StatusStream.swift    WebSocket + Auto-Reconnect
│   └── Discovery.swift       Bonjour NWBrowser
└── Views/
    ├── RootView.swift        TabView + Notaus-Overlay (folgt in 3b)
    └── SettingsTab.swift     Verbindung/Discovery
```

Die Tabs Auto / Manual / Parameter folgen in den nächsten Phasen (3c–3e).

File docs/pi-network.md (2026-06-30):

# Netzunabhängigkeit — Pi als WLAN-Access-Point

Damit die Maschine **ohne Heim-Router** steuerbar ist: Der Pi spannt sein eigenes
WLAN auf, das iPhone verbindet sich direkt. **App, Backend, Bonjour (`stopf.local`)
laufen unverändert** — es ändert sich nur das Netz darunter.

```
Zuhause:    iPhone ─► Heim-WLAN ─► Pi (stopf.local)        [Client-Modus]
Unterwegs:  iPhone ─► WLAN "Stopfmaschine" ─► Pi (10.42.0.1) [AP-Modus]
```

> Voraussetzung: Raspberry Pi OS **Bookworm** (nutzt NetworkManager). Prüfen mit
> `systemctl status NetworkManager`. Bei älterem OS mit `dhcpcd` siehe
> [Anhang](#anhang-älteres-os-ohne-networkmanager).

---

## Wichtig vorab: nur EIN WLAN-Radio

Der Pi Zero 2 W hat eine einzige Funkeinheit. Er ist **entweder** im Heim-WLAN
**oder** Access Point — nicht beides gleichzeitig. Im AP-Modus hat der Pi also
**kein Internet** (kein `apt`, kein `git pull`). Für Updates kurz zurück in den
Client-Modus.

---

## Umschalten

Beide Skripte liegen in `backend/pi/scripts/` und sind über `setup.sh` schon
auf dem Pi.

**In den AP-Modus (eigenes WLAN):**
```bash
cd ~/stopf/backend/pi
bash scripts/ap-mode.sh                       # SSID "Stopfmaschine", PW "stopfen2026"
bash scripts/ap-mode.sh MeinNetz GeheimesPW   # oder eigene Werte (PW >= 8 Zeichen)
```
Danach: iPhone-WLAN-Einstellungen → „Stopfmaschine" wählen → App öffnen.
Der Pi ist `http://10.42.0.1:8000` bzw. weiterhin `http://stopf.local:8000`.

**Zurück ins Heim-WLAN:**
```bash
cd ~/stopf/backend/pi
bash scripts/wifi-mode.sh
```

> **Die SSH-Sitzung bricht beim Umschalten ab** — das ist gewollt (das Radio
> wechselt das Netz). Die Skripte lösen den eigentlichen Wechsel per `systemd-run`
> von der Sitzung, der AP kommt also auch nach dem Abbruch sauber hoch. Danach
> einfach neu verbinden (im jeweils anderen Netz).

---

## Option A: AP immer an (einfachste Feld-Nutzung)

Wenn die Maschine fast immer unterwegs läuft, soll der AP beim Booten automatisch
starten. AP-Profil auf autoconnect setzen:
```bash
sudo nmcli connection modify stopf-ap connection.autoconnect yes
```
Dann ist der Pi nach jedem Einschalten direkt sein eigenes WLAN. Für Updates
zuhause `wifi-mode.sh` (schaltet AP ab, Heim-WLAN greift).

---

## Option B: Automatischer Fallback (Heim-WLAN wenn da, sonst AP)

Das Beste für „zuhause am Router, unterwegs autark" — NetworkManager bevorzugt
das Heim-WLAN und fällt nur auf den AP zurück, wenn keins erreichbar ist:

```bash
# Heim-WLAN hohe Priorität:
sudo nmcli connection modify "<HEIM-SSID>" connection.autoconnect-priority 10

# AP niedrige Priorität, aber autoconnect an:
sudo nmcli connection modify stopf-ap connection.autoconnect yes \
     connection.autoconnect-priority 1
```
Beim Boot verbindet sich der Pi mit dem Heim-WLAN, falls in Reichweite —
sonst aktiviert er den AP. Kein zusätzliches Dienst-/Dispatcher-Skript nötig.

> `<HEIM-SSID>` ist der Profilname; auflisten mit
> `nmcli -t -f NAME,TYPE connection show | grep wireless`.

---

## Verifizieren

1. AP aktivieren, am iPhone/Mac das WLAN „Stopfmaschine" beitreten
2. Browser: `http://10.42.0.1:8000/` → JSON mit `version` erscheint
3. `http://stopf.local:8000/docs` → Swagger (mDNS über AP funktioniert)
4. App → Tab Verbindung → Pi via Bonjour finden, oder `10.42.0.1` / Port `8000`
5. Zurückschalten: `wifi-mode.sh`, am Mac `ping stopf.local`

---

## Caveats

- **Kein Internet im AP-Modus** (Single-Radio) → Updates im Client-Modus.
- **SSH-Abbruch beim Umschalten** ist normal (siehe oben).
- **2,4 GHz only** — der Pi Zero 2 W kann kein 5 GHz; der AP ist 2,4-GHz-`bg`.
- **Stromversorgung:** AP-Betrieb zieht etwas mehr Strom — auf ein solides 5-V-Netzteil achten (Brownouts killen sonst WLAN).
- **Passwort ändern:** Default `stopfen2026` ist öffentlich (steht hier) — beim ersten echten Einsatz ein eigenes setzen.

---

## Anhang: älteres OS ohne NetworkManager

Falls `systemctl status NetworkManager` „not found" liefert (altes Pi OS mit
`dhcpcd`), bräuchte es den klassischen Weg mit `hostapd` + `dnsmasq` + statischer
`dhcpcd.conf`. Empfehlung: stattdessen auf Bookworm neu flashen — die
NetworkManager-Lösung oben ist deutlich wartungsärmer.

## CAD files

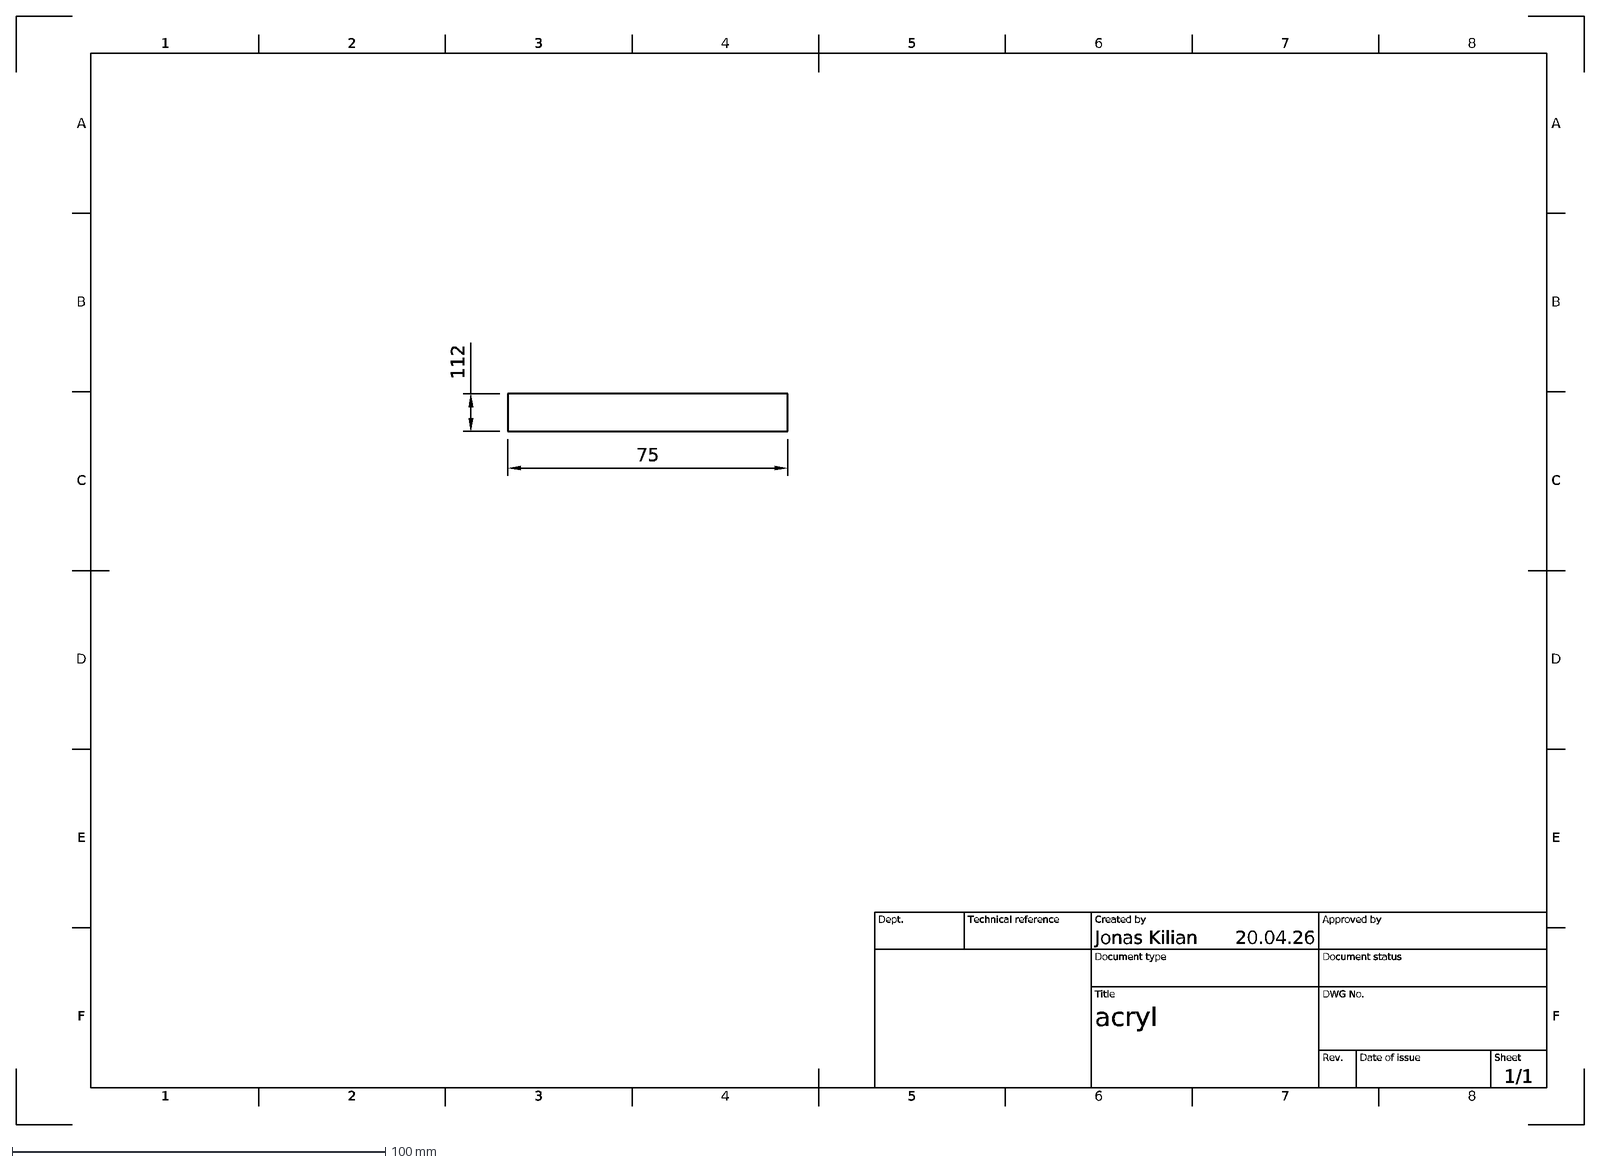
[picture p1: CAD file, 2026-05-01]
cad/drawings/acryl_parts/acryl_teil4.dxf
1
A
2
3
4
5
6
7
8
B
C
D
E
F
20.04.26
1/1
acryl
Jonas Kilian
Dept.
Technical reference
Created by
Approved by
Document type
Document status
Title
DWG No.
Rev.
Date of issue
Sheet
75
112

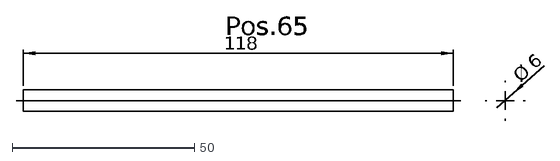
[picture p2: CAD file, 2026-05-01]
cad/reference/metal_parts/Metal_part_Pos_65.dxf
118
Ø
6
Pos.65

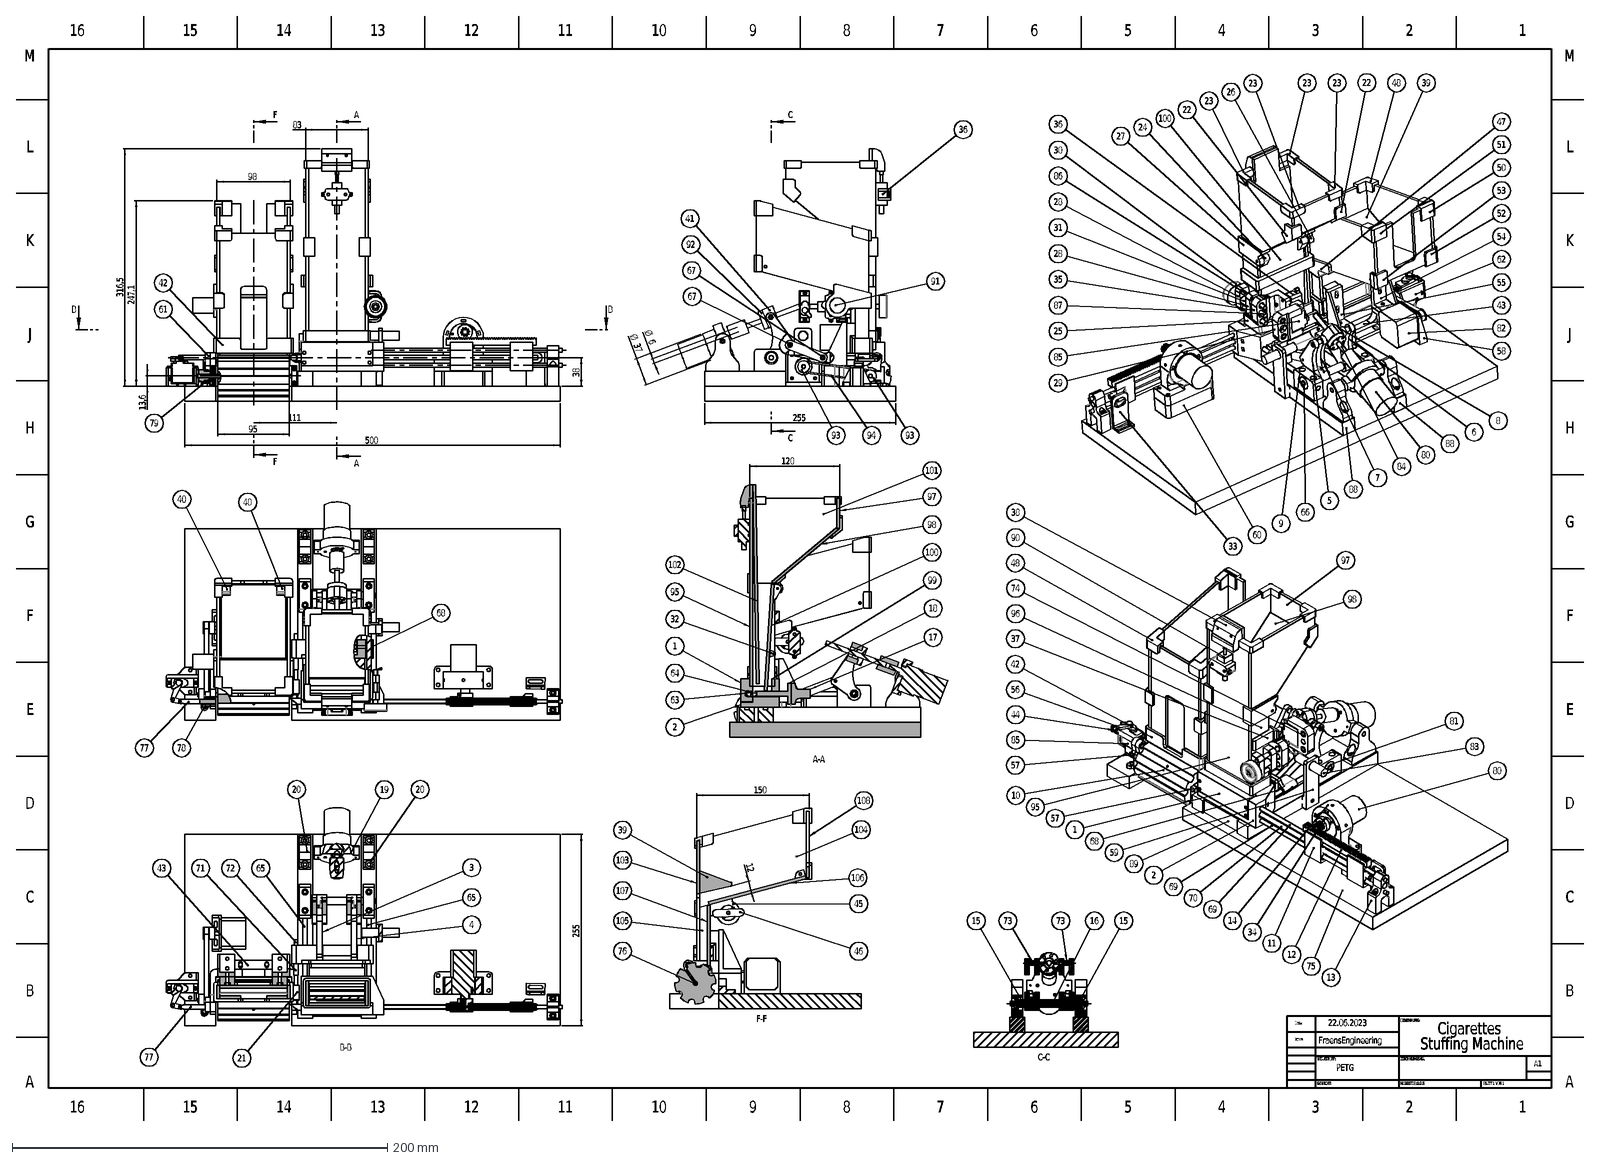
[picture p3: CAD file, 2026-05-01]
cad/source/Stuffing machine_00.DXF
PETG
FraensEngineering
22.06.2023
ZEICHNUNGSNR.
BENENNUNG:
WERKSTOFF:
Date
Drawn
Cigarettes
Stuffing Machine
MASSSTAB:1:2.5
BLATT 1 VON 1
A1
GEWICHT:
A
B
C
D
E
F
G
H
J
K
L
M
16
15
14
13
12
11
10
9
8
7
6
5
4
3
2
1
34
38
37
42
44
48
56
57
59
68
69
70
74
75
81
80
83
89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

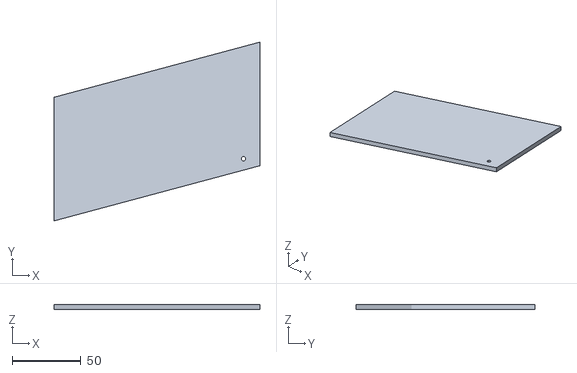
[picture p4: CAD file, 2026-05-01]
cad/stl/Part-97-Acryl.STL
150.0 x 130.2 x 4.00

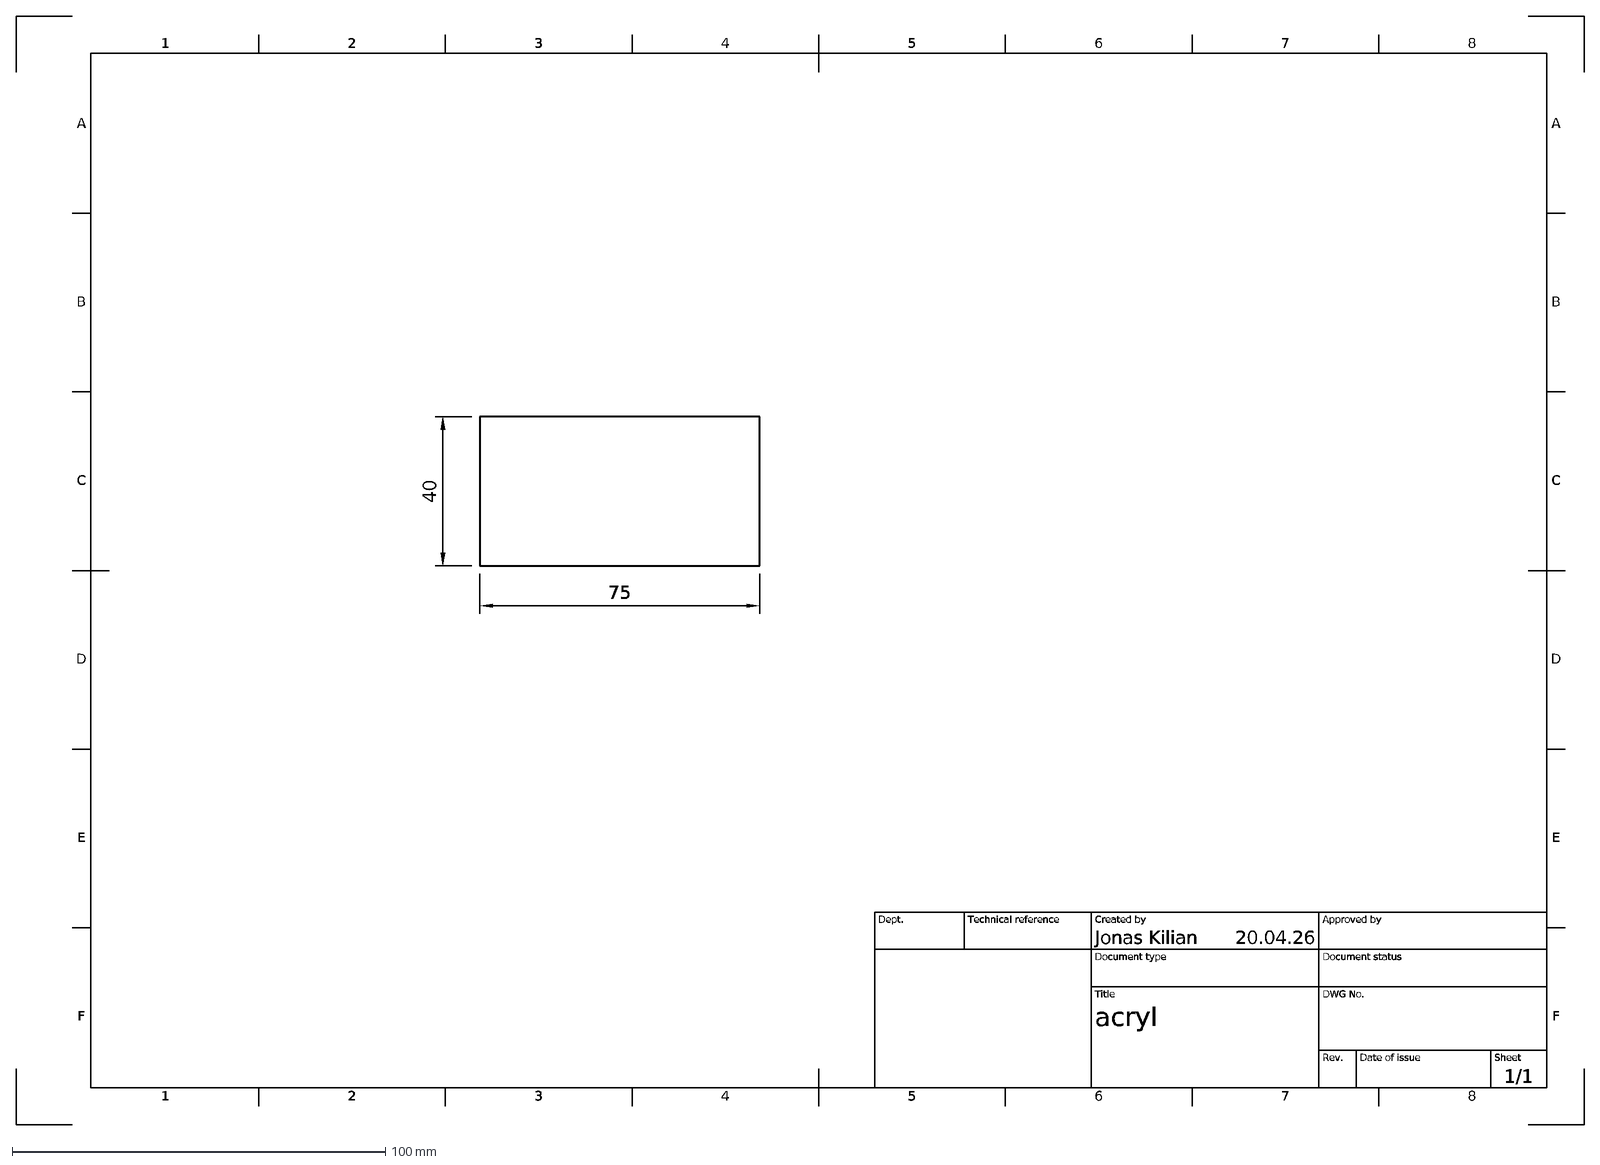
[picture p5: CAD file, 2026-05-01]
cad/drawings/acryl_parts/acryl_teil3.dxf
1
A
2
3
4
5
6
7
8
B
C
D
E
F
20.04.26
1/1
acryl
Jonas Kilian
Dept.
Technical reference
Created by
Approved by
Document type
Document status
Title
DWG No.
Rev.
Date of issue
Sheet
75
40

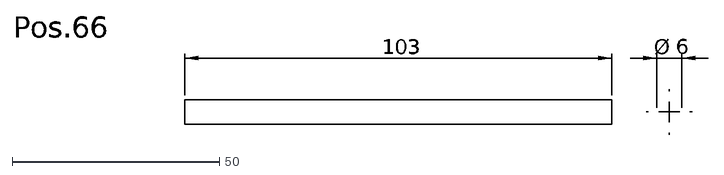
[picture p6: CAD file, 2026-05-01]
cad/reference/metal_parts/Metal_part_Pos_66.dxf
103
Ø
6
Pos.66

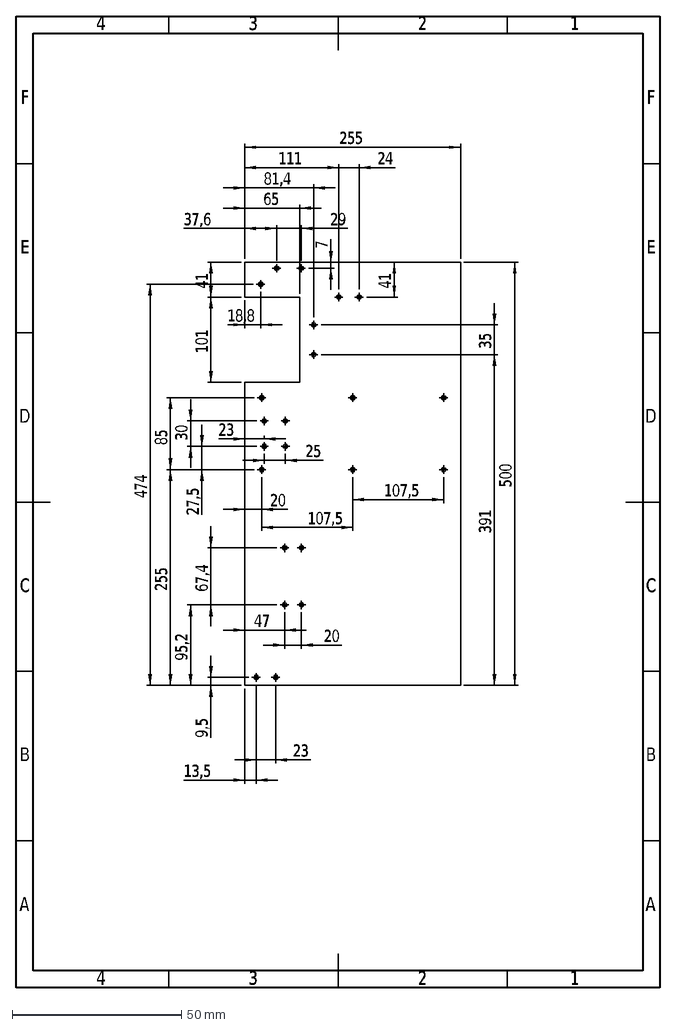
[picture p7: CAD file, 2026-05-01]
cad/source/Base plate Pos-75.DXF
A
B
C
D
E
F
4
3
2
1
500
255
41
101
65
9,5
13,5
23
95,2
67,4
47
20
107,5
85
27,5
30
25
474
18,8
391
35
81,4
37,6
29
7
111
24

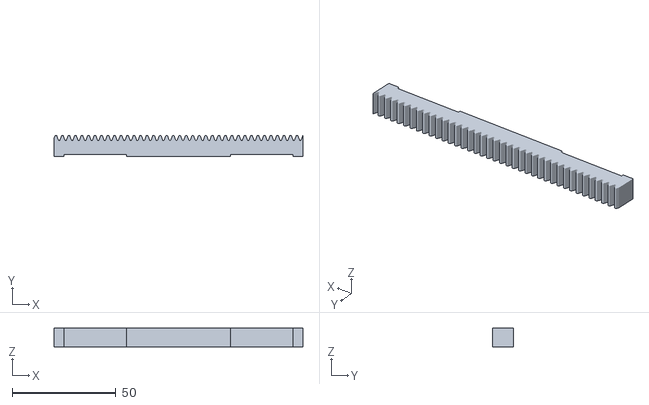
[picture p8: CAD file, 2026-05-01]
cad/stl/Part-10.STL
120.0 x 10.0 x 9.00

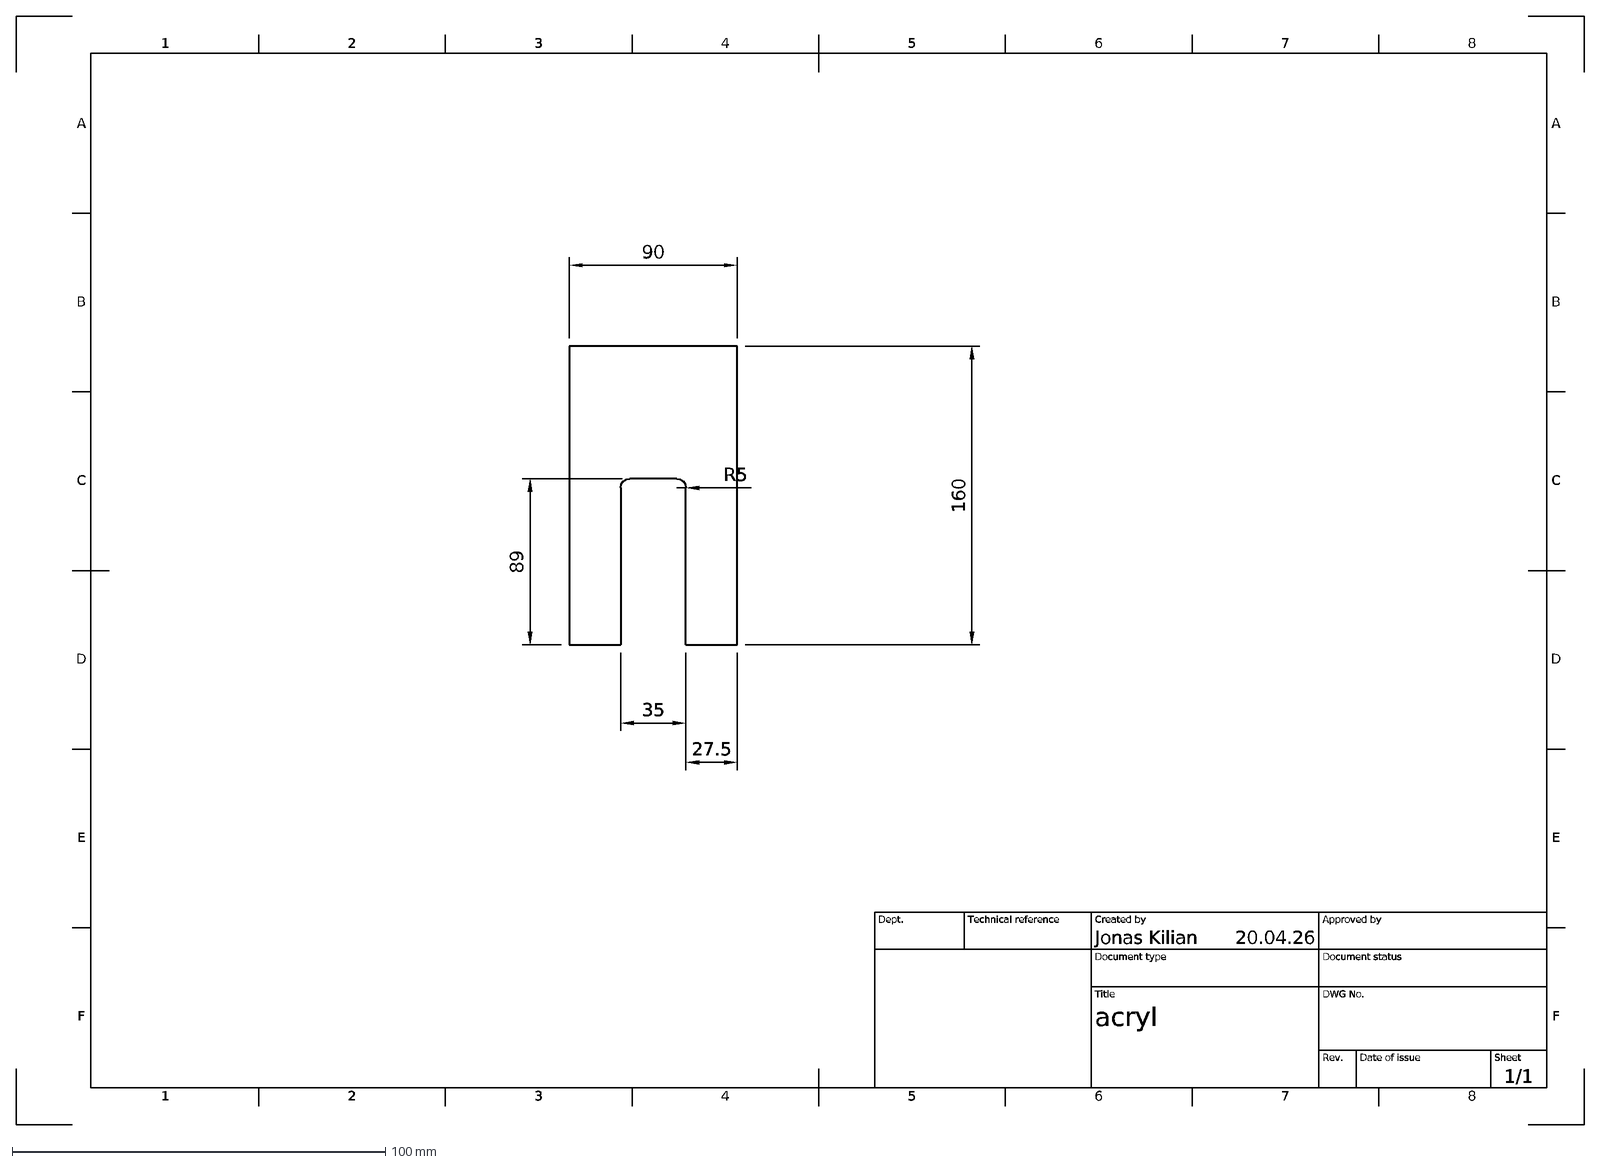
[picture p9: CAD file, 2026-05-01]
cad/drawings/acryl_parts/acryl_teil9.dxf
1
A
2
3
4
5
6
7
8
B
C
D
E
F
20.04.26
1/1
acryl
Jonas Kilian
Dept.
Technical reference
Created by
Approved by
Document type
Document status
Title
DWG No.
Rev.
Date of issue
Sheet
90
35
27.5
160
R5
89

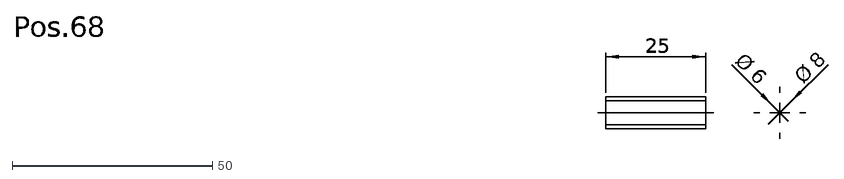
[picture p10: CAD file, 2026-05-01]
cad/reference/metal_parts/Metal_part_Pos_68.dxf
25
Ø
8
6
Pos.68

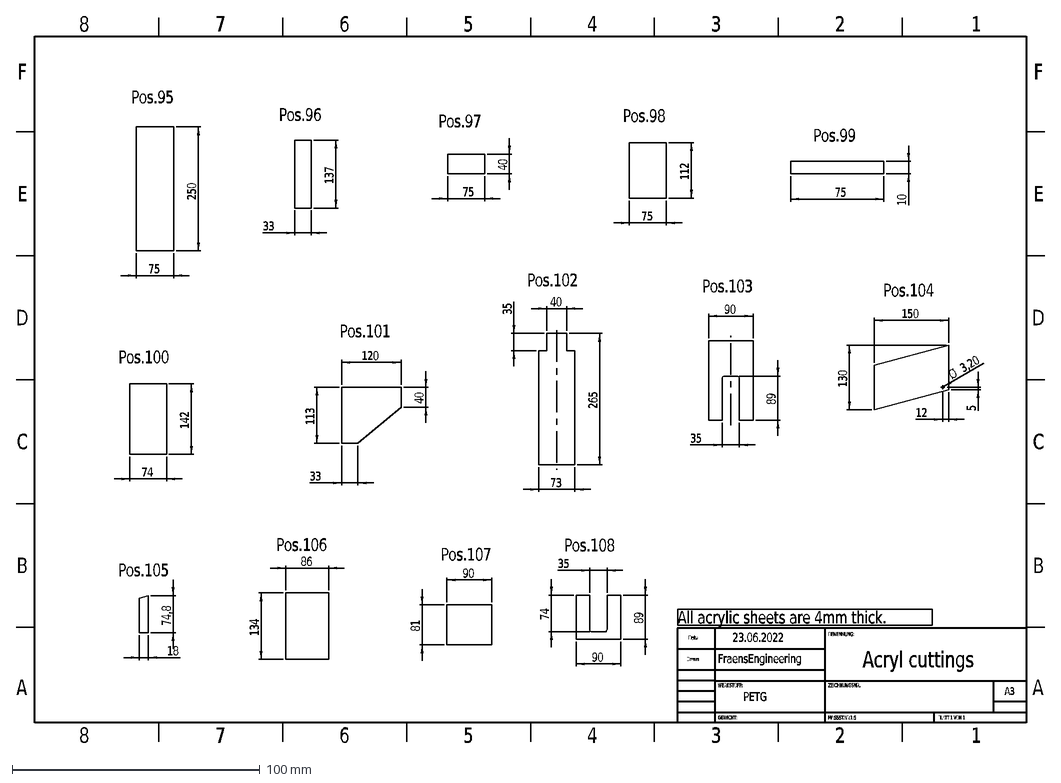
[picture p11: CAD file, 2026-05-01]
cad/source/Acryl cuttings_01.DXF
All acrylic sheets are 4mm thick.
GEWICHT:
A3
BLATT 1 VON 1
MASSSTAB:1:5
Acryl cuttings
Drawn
Date
WERKSTOFF:
BENENNUNG:
ZEICHNUNGSNR.
23.06.2022
FraensEngineering
PETG
A
B
C
D
E
F
8
7
6
5
4
3
2
1
250
75
Pos.95
137
33
Pos.96
40
Pos.97
112
Pos.98
10
Pos.99
74
142
Pos.100
120
113
Pos.101
265
73
35
Pos.102
90
89
Pos.103
150
130
12
Ø
3,20
Pos.104
18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

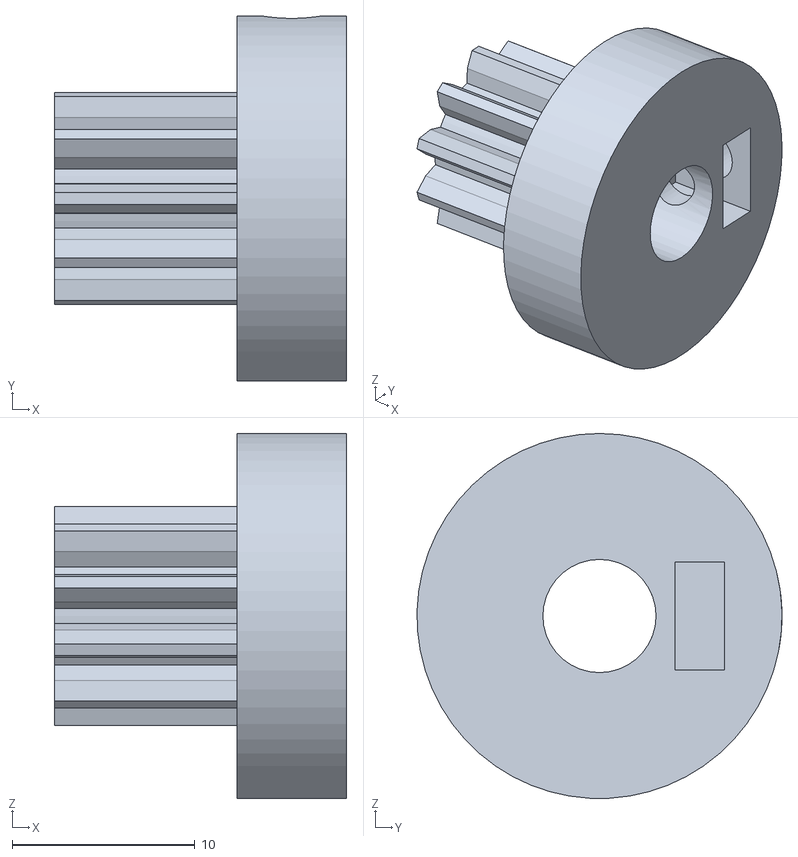
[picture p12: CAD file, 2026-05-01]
cad/stl/Part-31.STL
16.0 x 20.0 x 20.0

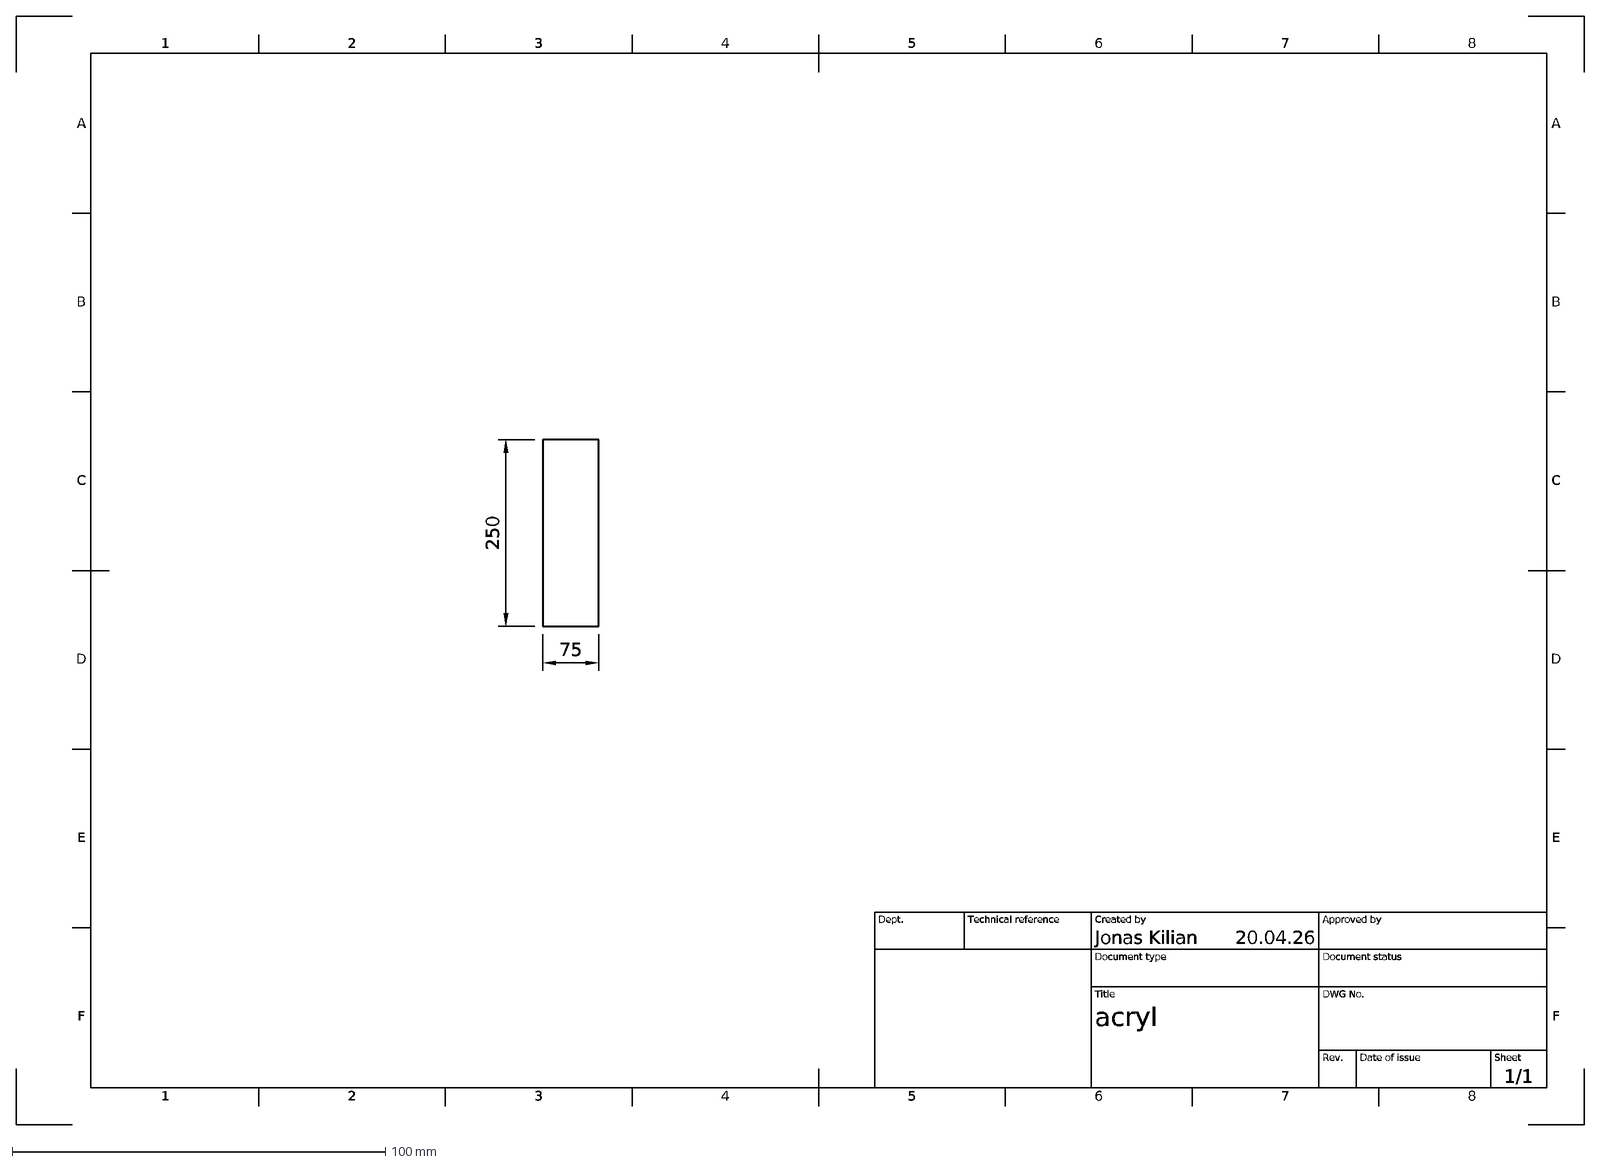
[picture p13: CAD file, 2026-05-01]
cad/drawings/acryl_parts/acryl_teil1.dxf
1
A
2
3
4
5
6
7
8
B
C
D
E
F
20.04.26
1/1
acryl
Jonas Kilian
Dept.
Technical reference
Created by
Approved by
Document type
Document status
Title
DWG No.
Rev.
Date of issue
Sheet
250
75

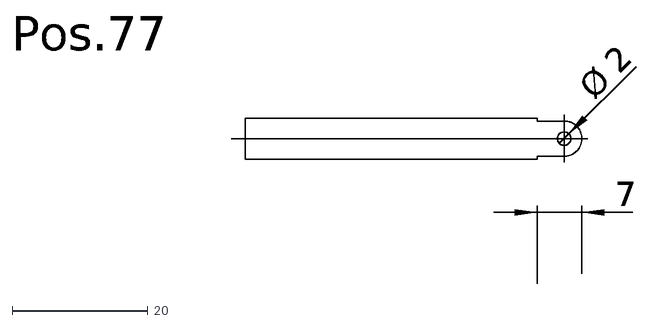
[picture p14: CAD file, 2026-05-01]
cad/reference/metal_parts/Metal_part_Pos_77.dxf
Ø
2
7
Pos.77

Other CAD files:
cad/source/Metal parts.DXF
cad/stl/Part-34.STL
cad/drawings/acryl_parts/acryl_teil2.dxf
cad/reference/metal_parts/Metal_part_Pos_74.dxf
cad/drawings/acryl_parts/acryl1.dxf
cad/drawings/acryl_parts/acryl2.dxf
cad/drawings/acryl_parts/acryl_teil10.dxf
cad/drawings/acryl_parts/acryl_teil11.dxf
cad/drawings/acryl_parts/acryl_teil12.dxf
cad/drawings/acryl_parts/acryl_teil13.dxf
cad/drawings/acryl_parts/acryl_teil14.dxf
cad/drawings/acryl_parts/acryl_teil5.dxf
cad/drawings/acryl_parts/acryl_teil6.dxf
cad/drawings/acryl_parts/acryl_teil7.dxf
cad/drawings/acryl_parts/acryl_teil8.dxf
cad/reference/metal_parts/Metal_part_Pos_63.dxf
cad/reference/metal_parts/Metal_part_Pos_64.dxf
cad/reference/metal_parts/Metal_part_Pos_67.dxf
cad/reference/metal_parts/Metal_part_Pos_69.dxf
cad/reference/metal_parts/Metal_part_Pos_70.dxf
cad/reference/metal_parts/Metal_part_Pos_71.dxf
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

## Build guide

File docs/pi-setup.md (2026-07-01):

# Raspberry Pi Zero 2 W — Setup

Schritt-für-Schritt vom leeren Pi bis zum laufenden Backend, das die iOS-App
und der Nano finden. Ziel: Der Pi ist als `stopf.local:8000` erreichbar und
startet das Backend automatisch beim Booten.

```
iPhone  ──WLAN──►  Pi Zero 2 W (stopf.local:8000)  ──USB──►  Arduino Nano
```

> Für den Betrieb **ohne Heim-Router** (Pi als eigener Access Point) siehe
> [pi-network.md](pi-network.md).

---

## 1. SD-Karte flashen (am Mac)

1. **Raspberry Pi Imager** installieren: <https://www.raspberrypi.com/software/>
2. Imager öffnen:
   - **Gerät:** Raspberry Pi Zero 2 W
   - **OS:** *Raspberry Pi OS Lite (64-bit)* — kein Desktop nötig, spart RAM
   - **Speicher:** deine SD-Karte
3. **⚙️ / „Weiter" → Einstellungen bearbeiten** (der wichtige Teil für headless):
   - **Hostname:** `stopf`  → damit wird der Pi automatisch `stopf.local`
   - **Benutzer:** `maschine` + Passwort (merken!)
   - **WLAN:** SSID + Passwort + Land (`DE`)
   - **SSH aktivieren** (Reiter „Dienste") → *Passwort-Authentifizierung*
4. Schreiben lassen, SD-Karte in den Pi, Strom dran.

> Erster Boot dauert 1–2 Min. Der Pi hängt sich ins WLAN und ist dann per SSH da.

---

## 2. Per SSH einloggen (am Mac)

```bash
ssh maschine@stopf.local
```

(Benutzernamen anpassen.) Beim ersten Mal Fingerprint mit `yes` bestätigen.

Falls `stopf.local` nicht auflöst → siehe [Troubleshooting](#troubleshooting).

---

## 3. Code auf den Pi bringen

**Variante A — git (wenn das Repo erreichbar ist):**
```bash
git clone https://github.com/JohnsonRepo/stopf.git ~/stopf
```

**Variante B — vom Mac kopieren (rsync):** auf dem **Mac** ausführen:
```bash
rsync -av --exclude '.venv' --exclude '.git' \
  "/Users/jonaskilian/Documents/Claude/Projects/stopf/stopfmaschine_starter/" \
  maschine@stopf.local:~/stopf/
```

Danach liegt das Backend unter `~/stopf/backend/pi`.

---

## 4. Setup-Skript ausführen (auf dem Pi)

```bash
cd ~/stopf/backend/pi
bash scripts/setup.sh
```

Das Skript erledigt automatisch:
- Systempakete (`python3-venv`, `avahi-daemon`)
- `dialout`-Gruppe (Serial-Zugriff ohne root)
- Serial-Port erkennen (CH340-Klon = meist `/dev/ttyUSB0`)
- venv + `pip install -r requirements.txt`
- Import-Test
- **systemd-Unit** mit deinem echten User/Pfad generieren + aktivieren
- **mDNS-Service** `_stopf._tcp` installieren

Am Ende steht eine Zusammenfassung. Wenn du neu zur `dialout`-Gruppe kamst:
```bash
sudo reboot
```

---

## 5. Nano anschließen

Nano per USB an den Pi (Micro-USB-Datenport, nicht nur PWR). Prüfen:

```bash
ls /dev/ttyUSB* /dev/ttyACM*      # sollte einen Port zeigen
journalctl -u stopfmaschine -f    # Log live; "Connected to Nano on ..." erwartet
```

Falls der Port von der Setup-Annahme abweicht, einmal anpassen:
```bash
sudo systemctl edit --full stopfmaschine   # Environment="STOPF_SERIAL_PORT=..." ändern
sudo systemctl restart stopfmaschine
```
> Das Backend macht zur Laufzeit ohnehin Auto-Detect über `ttyUSB`/`ttyACM`,
> der explizite Port ist nur die erste Wahl.

---

## 6. Verifizieren

**Auf dem Pi:**
```bash
curl http://localhost:8000/            # {"service":"stopfmaschine",...,"nano_connected":true}
curl http://localhost:8000/status      # geparster Maschinenstatus
```

**Am Mac (Browser):**
- `http://stopf.local:8000/docs` → interaktive API (Swagger)
- Dort `GET /params` testen → sollte die 18 EEPROM-Werte liefern

**Am iPhone:**
- App → Tab **Verbindung** → Pi sollte als *„Stopfmaschine on stopf"* erscheinen
- Antippen → verbindet → Sensor-Strip wird grün/live

---

## 7. Betrieb

| Aktion | Befehl |
|---|---|
| Status | `sudo systemctl status stopfmaschine` |
| Logs live | `journalctl -u stopfmaschine -f` |
| Neustart | `sudo systemctl restart stopfmaschine` |
| Stoppen | `sudo systemctl stop stopfmaschine` |
| Nach Code-Update | `update.sh` (SSH) **oder** App → Verbindung → System → *Backend aktualisieren* |

Der Dienst startet automatisch beim Boot und nach Abstürzen (`Restart=on-failure`).

**Update aus der App:** Tab *Verbindung* → *System* → **Backend aktualisieren** löst
`git pull` + Abhängigkeiten + Dienst-Neustart auf dem Pi aus (nutzt intern
`update.sh`). Braucht Internet → nur im **Client-Modus**, nicht im AP-Modus.
Die App verliert kurz die Verbindung und ist nach ~30-60 s wieder da; die neue
Version steht dann unter *Verbindung testen*.

---

## 8. Sauberes Herunterfahren (wichtig!)

**Nie einfach den Strom (12 V) ziehen, während der Pi läuft** — ein hartes
Abschalten während eines SD-Schreibvorgangs kann das Dateisystem beschädigen
(dann bootet der Pi nicht mehr und muss neu geflasht werden).

Stattdessen den Pi vorher **sauber herunterfahren**:

- **In der App:** Tab *Verbindung* → *System* → **Pi herunterfahren** → warten bis
  die grüne LED aus ist → dann 12 V trennen. (`setup.sh` richtet die nötige
  `sudo`-Regel automatisch ein — nur `poweroff`/`reboot`, sonst nichts.)
- **Per SSH:** `sudo poweroff`, dann LED-Aus abwarten, dann Strom trennen.

### Kugelsicher: Read-only-Dateisystem (Overlay FS)

Für ein Gerät ohne echten Aus-Schalter ist das die robusteste Lösung — danach
kann **kein** Stromziehen mehr die Karte beschädigen:

```bash
sudo raspi-config        # → Performance Options → Overlay File System → Enable
sudo reboot
```

Das Root-Dateisystem liegt dann schreibgeschützt im RAM. **Nachteil:** Änderungen
(auch `update.sh`) sind erst nach Deaktivieren wieder dauerhaft:

```bash
sudo raspi-config        # Overlay FS → Disable
sudo reboot
# ... update.sh / Änderungen ...
sudo raspi-config        # Overlay FS → Enable
sudo reboot
```

Empfehlung: Erst alles fertig einrichten und testen, dann Overlay FS aktivieren.

---

## 9. Nano-Firmware aktualisieren (über den Pi)

Der Nano bleibt am Pi-USB — du musst ihn nicht abstecken. Die Firmware wird auf
dem **Mac** gebaut (dort läuft PlatformIO), das fertige `.hex` per `scp` auf den
Pi kopiert, und der Pi flasht mit `avrdude`.

**Auf dem Mac:**
```bash
cd "<Projektpfad>/firmware/nano"
pio run                                    # baut .pio/build/nano/firmware.hex
scp .pio/build/nano/firmware.hex maschine@stopf.local:/tmp/firmware.hex
```

**Auf dem Pi:**
```bash
cd ~/stopf/backend/pi
bash scripts/flash-nano.sh                 # stoppt Backend, flasht, startet Backend
```

Das Skript gibt den Serial-Port frei (Backend stoppen ist sonst der häufigste
Fehler), erkennt den Port automatisch und nutzt Baud **57600** (CH340-Klon mit
altem Bootloader). Bei `not in sync` mit `115200` erneut:
`bash scripts/flash-nano.sh /tmp/firmware.hex 115200`.

> Alternativ alles in einem vom Mac aus:
> ```bash
> ssh maschine@stopf.local "cd ~/stopf/backend/pi && bash scripts/flash-nano.sh"
> ```
> (vorher das `.hex` wie oben per scp kopieren)

### Flashen aus der App (ohne SSH)

Dafür muss der kompilierte Hex **im Repo** liegen (`firmware/nano/firmware.hex`).
Nach jeder Firmware-Änderung auf dem **Mac** einchecken:
```bash
cd firmware/nano && pio run && cp .pio/build/nano/firmware.hex firmware.hex
git add firmware.hex && git commit -m "fw: rebuild hex" && git push
```
Dann auf dem iPhone:
1. **Verbindung → System → Backend aktualisieren** (holt den neuen Hex per git pull)
2. **Verbindung → System → Nano-Firmware flashen** (zwei Bestätigungen)

Der Flash läuft im separaten Dienst `stopf-flash` (eigene cgroup), stoppt kurz
das Backend, flasht mit avrdude und startet das Backend wieder. **Während des
Flashens nicht den Strom trennen.** Nur im Ruhezustand möglich.

---

## Troubleshooting

**`stopf.local` löst nicht auf (Mac/iPhone finden den Pi nicht)**
- Pi und Gerät im **selben WLAN** (2,4 GHz — Pi Zero 2 W kann kein 5 GHz)?
- Per IP testen: am Pi `hostname -I`, dann `http://<IP>:8000/docs`
- avahi läuft? `systemctl status avahi-daemon`

**Backend startet nicht**
- `journalctl -u stopfmaschine -e` ansehen
- Häufig: venv-Pfad falsch (setup.sh erneut laufen lassen)

**Nano wird nicht gefunden (`nano_connected:false`)**
- `ls /dev/ttyUSB* /dev/ttyACM*` — Port da?
- `groups` muss `dialout` enthalten (sonst Reboot nach setup.sh)
- USB-Datenkabel, nicht nur Ladekabel?
- Anderer USB-Port am Pi (Zero 2 W: der mit „USB" beschriftete, nicht „PWR")

**iPhone findet Pi nicht via Bonjour**
- In der App manuell `stopf.local` + Port `8000` eintragen
- Local-Network-Permission beim ersten Start erlaubt?

**Verbindung klappt erst nach mehreren Versuchen / WLAN zeitweise weg**
- Klassiker beim Pi Zero 2 W: **WLAN-Energiesparmodus**. `setup.sh` schaltet ihn
  ab (`/etc/NetworkManager/conf.d/wifi-powersave-off.conf`). Sofort-Test:
  `sudo iwconfig wlan0 power off`.
- Prüfen ob aktiv: `iwconfig wlan0 | grep "Power Management"` → sollte `off` sein.
- Nach Boot braucht das Backend ~15-20 s, bis es erreichbar ist — kurz warten.
- Stabilste Adresse: im Router eine **DHCP-Reservierung** (feste IP) für den Pi.

**Pi wird nach 2-3 Neustarts instabil / muss neu geflasht werden**
- Ursache: **hartes Stromabschalten** + evtl. **Unterspannung** beschädigen die SD.
- Unterspannung prüfen: `vcgencmd get_throttled` → `0x0` = ok, sonst besseres/eigenes
  5-V-Netzteil (≥ 2 A, getrennt von der Motor-Schiene).
- **Endgültige Abhilfe: Overlay-FS aktivieren** (Abschnitt 8) — dann ist Stromziehen
  völlig ungefährlich.
- Gute Marken-SD-Karte (echte A1/A2) verwenden.

**pip-Install ist langsam / bricht ab (Pi Zero 2 W hat wenig RAM)**
- piwheels liefert vorgebaute ARM-Wheels — normalerweise kein Kompilieren nötig
- Bei OOM: temporär Swap erhöhen (`sudo dphys-swapfile ...`) oder Pakete einzeln

**Pi bootet gar nicht mehr / nicht im Netz (grüne LED flackert nicht)**
- Meist Folge von **hartem Stromabschalten** → SD-Karte korrupt.
- Per Mini-HDMI an Monitor prüfen (Dateisystem-Fehler sichtbar?).
- Lösung: SD **neu flashen** (Abschnitt 1), dann `git clone` + `setup.sh` —
  dank GitHub in ~15 Min wieder einsatzbereit.
- **Danach unbedingt** sauberes Herunterfahren nutzen (Abschnitt 8), sonst
  passiert es wieder.

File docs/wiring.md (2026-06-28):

# Verdrahtung & Schaltpläne

Alle Diagramme als Mermaid (rendern direkt auf GitHub) plus ASCII-Detailskizzen
für die kniffligen Stellen (Spannungsteiler, Servo-Entkopplung).

> **Quelle der Wahrheit für Pin-Nummern:** [`firmware/nano/src/pins.h`](../firmware/nano/src/pins.h)
> **Bauteilliste & Material:** [`../CLAUDE.md`](../CLAUDE.md)

---

## 1. Stromversorgung (Power Distribution)

```mermaid
flowchart LR
    PSU["12 V / 5 A<br/>Netzteil"] -->|+12 V| F1["F1<br/>5 A T<br/>5x20 mm"]
    F1 -->|12 V| BUS12["12 V Bus<br/>+ 470 uF Elko"]
    BUS12 -->|12 V| L298N_VS["L298N V_S<br/>Motor-12 V"]
    BUS12 -->|12 V| A4988_VMOT["A4988 V_MOT<br/>100 uF Elko PFLICHT"]
    BUS12 -->|12 V| F3["F3<br/>500 mA F"]
    F3 -->|12 V braun| INIT["Initiatoren<br/>LJ8A3-2-Z/BX 3 Stueck"]
    BUS12 -->|12 V| F2["F2<br/>1 A T"]
    F2 -->|12 V| BUCK["Buck-Konverter<br/>LM2596 / Mini360<br/>auf 5,0 V justiert"]

    BUCK -->|5 V min. 3 A| BUS5["5 V Bus"]
    BUS5 -->|GPIO Pin 2/6| PI["Raspberry Pi<br/>Zero 2 W"]
    BUS5 -->|VCC + 470 uF| SERVO["SG90 Servo"]
    BUS5 -->|optional| NANO_5V["Arduino Nano<br/>via USB vom Pi"]

    PI -->|USB Daten + 5 V| NANO["Arduino Nano"]

    GND_BUS["GEMEINSAME GND<br/>Netzteil - Pi - Nano - Buck<br/>A4988 - L298N - Servo"]
    PSU -.->|GND| GND_BUS
    BUCK -.->|GND| GND_BUS
    NANO -.->|GND| GND_BUS
    PI -.->|GND| GND_BUS
    L298N_VS -.->|GND| GND_BUS
    A4988_VMOT -.->|GND| GND_BUS
    SERVO -.->|GND| GND_BUS
    INIT -.->|blau / GND| GND_BUS

    classDef warn fill:#ffe4b5,stroke:#d2691e,stroke-width:2px;
    classDef fuse fill:#ffe0e0,stroke:#cc0000,stroke-width:2px;
    class GND_BUS warn;
    class F1,F2,F3 fuse;
```

### Sicherungs-Konzept

```
                                                                   ┌─► L298N (Motoren)
                                                                   │
12 V Netzteil ─►【F1: 5 A T, 5×20 mm】──► 12 V-Bus ─────────────────┼─► A4988 (Stepper)
                  in Halter mit Schraubklemmen,                    │
                  unmittelbar nach PSU-Ausgang                     │
                                                                   ├─►【F2: 1 A T】─► Buck → Pi/Servo
                                                                   │
                                                                   └─►【F3: 500 mA F】─► Initiatoren-12 V
```

| Sicherung | Wert | Charakteristik | Schutzobjekt | Begründung |
|---|---|---|---|---|
| **F1 Hauptsicherung** | 5 A T (träge) | 5×20 mm | Verkabelung 12 V-Bus, gegen PSU-Ausfall der OCP | passt zum 5-A-Netzteil; *träge* wegen Motor-Anlaufstrom (NEMA + 2× DC + Buck-Cap-Ladung gleichzeitig kann kurz > 4 A ziehen) |
| **F2 Buck-Eingang** | 1 A T | 5×20 mm | Pi + Servo + Logik | Pi+Servo zieht ≤ 700 mA; trennt Logikseite, falls Motor-Pfad einen Defekt hat |
| **F3 Initiator-Schiene** | 500 mA F (flink) | 5×20 mm | Sensor-Verkabelung | 3 Sensoren ziehen je ~10 mA; flink, weil dahinter keine induktive Last hängt |

### Glas oder Keramik — beides funktioniert

Bei **12 V DC** sind Glas- und Keramik-Schmelzsicherungen **elektrisch
gleichwertig**. Beides geht.

| | Glas | Keramik (HBC) |
|---|---|---|
| Preis pro Stück | ~0,30 € | ~1–2 € |
| Abschaltvermögen | 35 A @ 250 V AC | 1500 A @ 250 V AC |
| Lichtbogen-Verhalten | erlischt bei 12 V DC sowieso ohne Probleme | komplett gelöscht durch Sandfüllung |
| Verfügbarkeit | überall (Reichelt, Conrad, Amazon, Auto-Zubehör) | Spezial-Elektronik-Handel |
| Mein-Bauteil-Box-Faktor | meist da | seltener da, aber wenn → super |

- **Du hast Glas zur Hand?** Nimm Glas, völlig ausreichend.
- **Du hast Keramik zur Hand?** Nimm Keramik, sogar ein bisschen sicherer.
- **Beides nicht?** Bestelle Glas — günstiger, gleichwertig.

> **Wichtig:** Beide Typen müssen den **gleichen Wert** und die **gleiche
> Charakteristik** haben (T = träge, F = flink). Eine Keramik-5A-T verhält sich
> beim Auslösen identisch zu einer Glas-5A-T.

Keramik wird **zwingend** bei: AC-Netzseite (vor dem 12-V-Netzteil) oder
Hochstrom-Versorgung (Bleibatterie / 4S LiPo > 100 A Kurzschluss). Im 12 V-DC-Pfad
dieser Maschine ist es Wahl-Sache.

### Alternative: selbstrückstellende Polyfuses (PTC)

Wenn dir Sicherungswechsel zu lästig sind:

| Position | Bauteil | Trip-Strom | Hinweis |
|---|---|---|---|
| 12 V Hauptlinie | Bourns MF-R500 | 5 A | trippt langsamer (Sekunden), kühlt von selbst zurück |
| Buck-Eingang | Bourns MF-R110 | 1,1 A | gleiches Verhalten |

Nachteil: ungenauer als Schmelzsicherungen, langsamerer Trip — okay als "soft fuse" zusätzlich zu F1, **aber nicht als Ersatz für F1**, weil sie im Kurzschluss zu langsam sind.

### Bus-Verteilung praktisch — WAGO-Klemmen

Für den +12 V-Bus und vor allem den **GND-Sternpunkt** brauchst du eine
ordentliche Verteilung. Steckbrett ist hier **kein** geeignetes Bauteil
(Federkontakt-Widerstand 10–100 mΩ, max ~3 A, lockert sich vibrationsbedingt).

**Empfohlen: WAGO 221 Hebelklemmen** (oder kompatible Hebelklemmen anderer
Hersteller mit gleicher Pol-Anzahl).

| Pole | Beispiel-Modell | Querschnitt | Strom | Einsatzfeld |
|---|---|---|---|---|
| 3-fach | WAGO 221-413 | 0,2–4 mm² | 32 A | lokale Sub-Sternpunkte (z. B. 3× Initiator-blau) |
| 5-fach | WAGO 221-415 | 0,2–4 mm² | 32 A | +12 V-Bus (passt exakt: PSU+, L298N, A4988, F2, F3) |
| 8-fach | WAGO 221-418 | 0,2–4 mm² | 32 A | GND-Sternpunkt (8 Verbraucher) |
| **10-fach** | div. Hebelklemmen | 0,2–4 mm² | 32 A | **Optimum** — eine Klemme für GND, eine für +12 V |

### Verdrahtungsplan mit 2× 10-Pol-Klemme (empfohlen)

**Eine Klemme für GND-Sternpunkt:**

```
   GND-Sternpunkt (10-Pol):
   ┌────┬────┬────┬────┬────┬────┬────┬────┬────┬────┐
   │ 1  │ 2  │ 3  │ 4  │ 5  │ 6  │ 7  │ 8  │ 9  │ 10 │
   └────┴────┴────┴────┴────┴────┴────┴────┴────┴────┘
     │    │    │    │    │    │    │    │    │    │
     │    │    │    │    │    │    │    │    │    └─► Reserve
     │    │    │    │    │    │    │    │    └─────► Nano (optional, kommt via USB-Pi)
     │    │    │    │    │    │    │    └──────────► Pi GND (Pin 6)
     │    │    │    │    │    │    └───────────────► Initiator-blau (3× gebündelt, siehe unten)
     │    │    │    │    │    └────────────────────► Servo GND (braun)
     │    │    │    │    └─────────────────────────► A4988 GND_logic
     │    │    │    └──────────────────────────────► A4988 GND_motor
     │    │    └───────────────────────────────────► L298N GND
     │    └────────────────────────────────────────► Buck VOUT−
     └─────────────────────────────────────────────► PSU − (+ Buck VIN−)
```

**Eine Klemme für +12 V-Bus:**

```
   +12 V-Bus (10-Pol):
   ┌────┬────┬────┬────┬────┬────┬────┬────┬────┬────┐
   │ 1  │ 2  │ 3  │ 4  │ 5  │ 6  │ 7  │ 8  │ 9  │ 10 │
   └────┴────┴────┴────┴────┴────┴────┴────┴────┴────┘
     │    │    │    │    │    │
     │    │    │    │    │    └─► Reserve / Bulk-Cap +
     │    │    │    │    └──────► F3 → Initiator-braun-Schiene
     │    │    │    └───────────► F2 → Buck-Eingang +
     │    │    └────────────────► A4988 V_MOT
     │    └─────────────────────► L298N V_S
     └──────────────────────────► PSU + (über F1)
```

→ Saubere Stern-Topologie, jeder Pfad ein eigener Pin, keine Daisy-Chain.

### Initiator-blau bündeln (Sub-Sternpunkt)

Die 3 blauen Adern der Initiatoren würden 3 Pins belegen — Lösung: **vorher
zusammenfassen** in einem lokalen Sub-Sternpunkt nahe der Sensor-Schiene.

**Variante 1 (sauber): Mini-WAGO 3-Pol als Sub-Sternpunkt**

```
   3× Initiator blau (je 0,25 mm²) → WAGO 221-413 (3-Pol)
                                          │
                                          └─► eine 0,5 mm²-Litze →
                                              Haupt-GND-Klemme Pin 7
```

**Variante 2 (kompakter): 3 Litzen in eine Aderendhülse 1,5 mm²**

```
   3× Initiator blau (je 0,25 mm²) → 4× Aderendhülse 1,5 mm²
                                       (3 Litzen zusammen, gemeinsame Hülse)
                                       → Haupt-GND-Klemme Pin 7
```

→ Variante 1 ist sauberer und beschriftbar. Variante 2 spart das WAGO-Bauteil.

### Verdrahtungsplan mit nur 1× 10-Pol-Klemme

Priorisiere **GND** — wo Sterntopologie kritisch ist. Den +12 V-Bus dann als
Daisy-Chain über die Schraubklemmen der Module, da spielen 50 mV
Spannungsabfall keine Rolle.

```
   1× 10-Pol GND-Sternpunkt (wie oben)
   +12 V als Daisy-Chain:
     PSU+ ──[F1]──● L298N V_S ──● A4988 V_MOT ──● [F2] Buck+ ──● [F3] Init.+

   Aderquerschnitt: 1,0 mm² Hauptlinie, fest in jede Modul-Klemme rein und gleich
   wieder zur nächsten — kein Verteiler nötig dazwischen.
```

### Verdrahtungsplan mit 2× 5-Pol-Klemme (verkettet, Notlösung)

Wenn nur kleinere Klemmen da sind: zwei 5-fach-WAGOs ergeben verkettet einen
8-fach-Stern. Drahtbrücke zwischen je einem Pin der zwei WAGOs (5 cm
1,0 mm² massiv).

```
   GND-Stern (8 Anschlüsse aus 2× 5-Pin-WAGO):

   WAGO #2                            WAGO #3
   ┌────┬────┬────┬────┬────┐         ┌────┬────┬────┬────┬────┐
   │ 1  │ 2  │ 3  │ 4  │ 5  │ ◄────►  │ 1  │ 2  │ 3  │ 4  │ 5  │
   └────┴────┴────┴────┴────┘    ▲    └────┴────┴────┴────┴────┘
                                 │
                          Brücke 1,0 mm²
                          1× Pin pro WAGO
```

### Beschriftung der Klemme

Mit **wasserfestem Marker** direkt auf das transparente Klemmen-Gehäuse,
welcher Pin wozu:

```
   ┌─────┬─────┬─────┬─────┬─────┬─────┬─────┬─────┬─────┬─────┐
   │PSU- │Buck │Buck │L298 │A4988│A4988│Serv │Init │ Pi  │Res. │
   │     │VIN- │VOUT-│GND  │MOT  │LOG  │GND  │blau │GND  │     │
   └─────┴─────┴─────┴─────┴─────┴─────┴─────┴─────┴─────┴─────┘
```

In 6 Monaten beim Debuggen wirst du es dir selbst danken.

### Best Practices

- WAGOs mit Klebepad (Tesa Powerstrips) oder DIN-Schiene am Gehäuse fixieren
- Filzstift-Beschriftung pro Pin: "PSU−", "L298N", "A4988_motor", "A4988_logic", …
- Alle GND-Drähte einzeln in **separate** Pins, **keine Daisy-Chain**
- Querschnitt ≥ 0,75 mm² für Hochstrom-Pfade (PSU, L298N), ≥ 0,5 mm² für Logik

> **Verboten:** Daisy-Chain ("PSU → Buck → Pi → L298N → A4988 → GND") — wenn der
> Press-Motor 3 A zieht, fließen die durch alle vorgelagerten GND-Leitungen →
> 100 mV Massepotential-Verschiebung am Pi → Logikfehler oder USB-Ausfall.

### Wichtige Regeln

| Regel | Warum |
|---|---|
| **F1 unmittelbar nach PSU-Ausgang** (nicht erst nach 1 m Kabel) | Sicherung schützt das Kabel — wenn das Kabel vor der Sicherung schmort, hat sie nichts genützt |
| **Sicherungshalter mit Schraubklemmen**, kein Steckhalter | DIY-Vibrationen lockern Stecker; lose Sicherung = Lichtbogen |
| **Buck-Konverter VOR Anschluss auf exakt 5,0 V justieren** (Multimeter!) | werkseitig oft auf 1,2 V — würde Pi/Servo grillen |
| **A4988 V_MOT: 100 µF Elko zwingend** zwischen V_MOT und GND, < 5 cm vom IC | sonst zerstören Spannungsspitzen den Treiber |
| **L298N: 470 µF Elko** an 12 V-Eingang | DC-Motor-Anlaufstrom dämpfen |
| **Servo NICHT vom L298N-5 V-Ausgang** speisen | bricht unter Motorlast ein, Servo zappelt |
| **Servo VCC: 470 µF Elko direkt an VCC↔GND** | Servo-Anlaufstrom |
| **ALLE GNDs verbinden** (Sternpunkt am Netzteil) | sonst funktionieren Steuersignale unzuverlässig |
| **Pi NICHT über Micro-USB** speisen | Polyfuse begrenzt → Brownout. Statt: GPIO Pin 2 (5 V) + Pin 6 (GND) |
| **Bei AC-Netzseite Keramik-Sicherung verwenden** (im 12-V-Netzteil verbaut, sonst extern primärseitig) | für 230 V AC ist Keramik-HBC Pflicht (VDE/CE) — Glas würde Lichtbogen weiterführen |

---

## 2. Signalverdrahtung Arduino Nano

```mermaid
flowchart LR
    subgraph NANO [Arduino Nano]
        D2["D2 STEP"]
        D3["D3 DIR"]
        D4["D4 EN"]
        D5["D5 PRESS_ENA PWM"]
        D6["D6 PUSHER_ENB PWM"]
        D7["D7 PRESS_IN1"]
        D8["D8 PRESS_IN2"]
        D9["D9 PUSHER_IN3"]
        D10["D10 PUSHER_IN4"]
        D11["D11 Servo Huelse PWM"]
        D12["D12 Hopper-MOSFET"]
        D13["D13 Solenoid2-MOSFET"]
        A0["A0 Init Press"]
        A1["A1 Init PushFront"]
        A2["A2 Init PushRear"]
        A4["A4 Solenoid1-MOSFET"]
        A5["A5 Magazin-Sensor"]
    end

    D2 --> A4988["A4988<br/>STEP/DIR/EN<br/>zu NEMA 17"]
    D3 --> A4988
    D4 --> A4988

    D5 --> L298N_A["L298N Kanal A<br/>ENA PWM + IN1/IN2 Richtung<br/>zu DC-Motor Presse"]
    D7 --> L298N_A
    D8 --> L298N_A

    D6 --> L298N_B["L298N Kanal B<br/>ENB PWM + IN3/IN4 Richtung<br/>zu DC-Motor Pusher"]
    D9 --> L298N_B
    D10 --> L298N_B

    D11 --> SERVO["SG90 Servo<br/>Huelsen-Schieber (einziger Servo)"]

    A4 --> MOS1["MOSFET IRLZ44N<br/>+ 1N5819 Flyback<br/>zu Solenoid Heschen HS-0530B (Front-Knock)"]
    D13 --> MOS2["MOSFET IRLZ44N<br/>+ 1N5819 Flyback<br/>zu Solenoid Heschen HS-0530B (Top-Druck)"]
    D12 --> MOS3["MOSFET IRLZ44N oder 2N7000<br/>+ 1N4148 Flyback<br/>zu Huelsenmagazin-Motor 5V"]

    DIV1["Spannungsteiler<br/>10 k + 7,5 k"] --> A0
    DIV2["Spannungsteiler<br/>10 k + 7,5 k"] --> A1
    DIV3["Spannungsteiler<br/>10 k + 7,5 k"] --> A2

    INIT_P["Initiator Press<br/>LJ8A3-2-Z/BX NPN"] -->|schwarz Signal 12 V| DIV1
    INIT_PF["Initiator Push-Front"] -->|schwarz| DIV2
    INIT_PR["Initiator Push-Rear"] -->|schwarz| DIV3

    OPTO["Gabellichtschranke<br/>Magazin-Index"] --> A5
```

---

## 3. Initiator-Spannungsteiler (KRITISCH)

NPN-Initiatoren geben das Signal als **12 V Pull-up** aus → würde 5 V-Eingang
des Nano sofort zerstören. Spannungsteiler-Verhältnis:

```
U_out = U_in · R2 / (R1 + R2)
      = 12 V · 7,5 kΩ / (10 kΩ + 7,5 kΩ)
      = 12 V · 7,5 / 17,5
      ≈ 5,14 V       ← noch innerhalb 5 V-Toleranz des Nano (max 5,5 V)
```

### ASCII-Schaltbild pro Sensor (3× identisch für Press / PushFront / PushRear)

```
  Initiator LJ8A3-2-Z/BX oder LJ12A3-4-Z/BX (NPN, 12 V)
  ┌──────────────────────┐
  │  braun  ──────────── │ ◄──── +12 V Versorgung (über F3)
  │  blau   ──────────── │ ◄──── GND (gemeinsame Masse!)
  │  schwarz ─── Signal  │
  └──────────────┬───────┘
                 │
                 ●  Sensor inaktiv → ~12 V (interne LED wirkt als Pull-up)
                 │  Sensor aktiv (Metall vor Sensor) → 0 V (zieht auf GND)
                 │
                 ▼  ── verdrilltes Kabel zum Nano ──
                 ▼     (Schwarz + Blau twisten gegen EMV)
                 │
        ┌────────●────────┐  ◄── Spannungsteiler nahe AM NANO platzieren,
        │                 │      nicht am Sensor (12 V auf Kabel = robust)
       ┌┴┐                │
       │ │ R1 = 10 kΩ     │
       │ │ (1/4 W)        │
       └┬┘                │
        │                 │
        ●─────────────────●──────► A0 / A1 / A2 am Nano
        │                 │
       ┌┴┐               ┌┴┐
       │ │ R2 = 7,5 kΩ   │ │ C = 47 nF Keramik
       │ │               │ │ (parallel zu R2 → EMV-Filter)
       └┬┘               └┬┘
        │                 │
        ●─────────────────●
        │
       ─┴─  GND (Sternpunkt)
```

> **Logik im Code:** `INIT_TRIGGERED_LEVEL = LOW`
> ([`firmware/nano/src/config.h`](../firmware/nano/src/config.h))
> Sensor "sieht" Metall → Output zieht auf GND → Spannungsteiler liefert 0 V → `digitalRead == LOW`.

### Was beim Spannungsteiler beachten

| Punkt | Empfehlung | Warum |
|---|---|---|
| **Position** | Widerstände + C **am Nano-Pin**, nicht am Sensor | 12 V-Signal auf der Leitung → besseres SNR gegen Motor-EMI |
| **R-Werte** | 10 kΩ + 7,5 kΩ (Nano) bzw. 10 kΩ + 3,9 kΩ (ESP32) | erprobt, P_dissipation < 5 mW |
| **R-Toleranz** | 5 % reicht (Standardwiderstand) | 1 % nur für maximalen Geiz an Genauigkeit |
| **R-Leistung** | 1/4 W (250 mW) — billige Standardware | tatsächliche Belastung ~5 mW, 50× Reserve |
| **Filter-C** | **47 nF Keramik parallel zu R2** | dämpft Motor-PWM-Stör­spitzen (~1–30 kHz), Sensor-Latenz nur ~3 ms |
| **Kabel** | Sensor-Kabel verdrillen (schwarz + blau) | Common-Mode-EMI wird ausgemittelt |
| **GND** | Sensor-GND auf den **Sternpunkt** am Netzteil, nicht "irgendwo" | sonst verschiebt Sensor-Strom den Mittenabgriff |
| **Pull-up** | nicht zwingend (LED-Pull-up im Sensor reicht meist) | Falls "schwarz" im Leerlauf < 10 V: 4,7 kΩ extern von schwarz nach +12 V |

### Test vor dem Anschluss am Nano (Pflicht-Checkliste)

```
□ 1) Sensor mit 12 V versorgen (braun an +12 V via F3, blau an GND)
□ 2) Spannungsteiler aufbauen (R1, R2, C), GND mit Sensor-GND verbinden
□ 3) Multimeter zwischen Mittenabgriff und GND messen
□ 4) Sensor inaktiv: Erwartung 5,0–5,2 V (kein Metall davor)
□ 5) Sensor aktiv: Erwartung 0,0–0,2 V (Schraubenzieher 1–2 mm davor)
□ 6) Sensor mehrfach aktivieren, beide Werte stabil reproduzierbar
□ 7) Optional: Funktion mit laufendem Motor in der Nähe verifizieren
   (Stör­einflüsse vorhanden, falls C zu klein gewählt)
□ 8) ERST DANN Verbindung zu A0/A1/A2 am Nano herstellen
```

> Wenn Schritt 4 statt 5 V dauerhaft 12 V zeigt: R1/R2 vertauscht — würde
> den Nano-Pin sofort zerstören. **Fehler hier ist 100 % vermeidbar.**

### Filter-Kondensator: Wahl der Kapazität

| C-Wert | Grenzfrequenz f_c | Sensor-Latenz | Geeignet für |
|---|---|---|---|
| 10 nF | ~3,7 kHz | ~0,4 ms | Schnelle Sensor-Reaktion, leichte EMV |
| **47 nF** ← Default | ~800 Hz | ~2 ms | Mittelweg, gut gegen Motor-PWM 1–30 kHz |
| 100 nF | ~370 Hz | ~4 ms | Maximale Filterung, langsamere Reaktion |
| 1 µF | ~37 Hz | ~40 ms | Nur wenn Polling sehr langsam (z. B. 1 Hz) |

> **f_c-Berechnung:** `f_c = 1 / (2π · R_T · C)` mit `R_T = R1 ∥ R2 ≈ 4,3 kΩ`

### Für ESP32 (Übergangslösung, 3,3 V-Logik)

```
R1 = 10 kΩ, R2 = 3,9 kΩ, C = 47 nF (gleiche Wahl wie Nano)
U_out = 12 V · 3,9 / 13,9 ≈ 3,37 V    ← innerhalb 3,3 V-Toleranz (max 3,6 V)
```

### Ersatzwerte falls 7,5 kΩ nicht vorrätig

7,5 kΩ ist Standard, aber nicht in jedem Basis-Sortiment. Diese Alternativen funktionieren ebenfalls (Ziel: U_out zwischen 3,5 V und 5,4 V):

| R1 | R2 | U_out | Bewertung |
|---|---|---|---|
| 10 kΩ | **6,8 kΩ** | 4,86 V | ✅ idealer Ersatz (Standardwert, etwas mehr Reserve) |
| 10 kΩ | 7,5 kΩ | 5,14 V | ✅ Standard |
| 10 kΩ | **5,6 kΩ + 2 kΩ in Reihe** = 7,6 kΩ | 5,18 V | ✅ Reihenschaltung addiert, falls Einzelwerte fehlen |
| 10 kΩ | 8,2 kΩ | 5,41 V | ⚠️ knapp unter 5,5 V max — geht, aber wenig Reserve |
| 10 kΩ | 10 kΩ | 6,00 V | ❌ zu hoch für 5 V-Nano |

> **Reihenschaltung addiert** (R_gesamt = R1 + R2 + …), **Parallelschaltung verkleinert** (1/R_gesamt = 1/R1 + 1/R2 + …). Für R2-Ersatz brauchst du **Reihe**.

### Physischer Aufbau auf Lochraster / Steckbrett

| Verbindung | Wie |
|---|---|
| Widerstand ↔ Widerstand (z. B. 5,6k + 2k) | **direkt Bein-an-Bein verlöten**, Beine vorab haken, dann Schrumpfschlauch drüber. Keine Litze dazwischen — weniger Lötstellen = robuster |
| Sensor schwarz → R1 | Litze (langer Weg zum Sensor) |
| Abgriff (R1↔R2-Knoten) → Nano A0 | Litze |
| C (47 nF) → GND und R2 → GND | **lokal an einem Punkt** zusammenführen (kurze Lötbrücke), **dann EIN Draht** zum Sternpunkt |
| Aufbauort | Test-Phase: Steckbrett (Signal-mA → unkritisch). Final: kleine Lochrasterplatine **nahe am Nano** |

> ⚠️ **C-GND und R2-GND müssen lokal zusammen.** Wenn beide auf separaten langen Drähten zum Sternpunkt laufen, wird die Filterschleife groß → der 47-nF-Kondensator filtert nichts mehr. Gleiches Prinzip wie beim Elko: lokal puffern, dann **ein** sauberer Draht zur Masse.

### Mechanische Montage der Initiatoren

| Sensor | Gewinde | Bohrung in Halterung |
|---|---|---|
| LJ8A3-2-Z/BX | **M8×1 Feingewinde** | **8,5 mm Durchgangsloch** (kein Gewinde schneiden) |
| LJ12A3-4-Z/BX | **M12×1 Feingewinde** | **12,5 mm Durchgangsloch** |

> ⚠️ **Feingewinde (×1), nicht Regelgewinde** (M12 Regel wäre ×1,75). Falls du Muttern separat kaufst: **M8×1 / M12×1 fein** verlangen.

**Montage in 4 mm Acryl (PMMA):**
- 2 Sechskant-Kontermuttern liegen dem Sensor i. d. R. bei
- **Unterlegscheiben** unter beide Muttern (PMMA verteilt Druck schlecht, sonst Risse)
- **Handfest + ¼ Umdrehung** — nicht überdrehen
- **Kein Gewinde ins Acryl schneiden** — hält in 4 mm nicht
- Vorteil Durchgangsloch + Kontermutter: Schaltabstand bleibt nachjustierbar

**Montage in 3D-Druck:**
- 12,5 mm Durchgangsloch + Sechskant-Mutter-Tasche im Druck
- Oder M12×1-Gewinde direkt mit drucken (geht, aber Mutter-Variante haltbarer)

### Sensor-Test mit der Sensor-eigenen LED (schnellste Diagnose)

Vor jeder Multimeter-/Nano-Diagnose: **die LED am Sensor selbst beobachten.**
Die meisten LJ-Sensoren haben eine kleine rote/gelbe LED, die bei Detektion leuchtet — **unabhängig vom Nano und vom Spannungsteiler**.

```
12 V an Sensor (braun=+12V, blau=GND), Sensor sonst nirgendwo angeschlossen
[große Stahl-Schraube direkt auf die Sensor-Stirnfläche]
   LED an?  → Sensor funktioniert. Problem liegt im Spannungsteiler/Signal-Pfad
   LED aus? → Sensor erkennt nicht. Material/Abstand/Größe prüfen (Tabelle unten)
```

### Target-Material und -Größe (oft unterschätzt!)

Der Schaltabstand Sn (LJ8: 2 mm, LJ12: 4 mm) gilt für **Stahl-Target ≥ 3× Sn Kantenlänge** (LJ8: ≥ 6×6 mm, LJ12: ≥ 12×12 mm). Real:

| Target-Material | Anteil von Sn | Beispiel |
|---|---|---|
| Stahl / Eisen | 100 % | M8-Schraubenkopf flach ✅ |
| **Edelstahl V2A** | **70–85 %** | dein Standard-Pusher-Target — Sn LJ12 real nur ~3 mm |
| Aluminium | 30–40 % | praktisch nicht brauchbar |
| Messing / Kupfer | 30–40 % | praktisch nicht brauchbar |
| Plastik / Holz | 0 % | kein Signal |

> **Konsequenz:** Pusher-Target am besten aus **mildem Stahl**, nicht V2A — bringt vollen Schaltabstand und Reserve gegen Verschmutzung.

### Initiator-Troubleshooting

| Symptom | Wahrscheinliche Ursache | Behebung |
|---|---|---|
| **Abgriff zeigt ~12 V statt 5 V** | Multimeter steht VOR R1 ODER R1 nicht in Reihe ODER R2 fehlt | Topologie mit Ohm-Messung prüfen: 10 kΩ über R1, 7,5 kΩ über R2. Sofort vom Nano abklemmen wenn 12 V! |
| Abgriff zeigt 0 V (egal ob Metall) | schwarze Litze lose / Kurzschluss zu GND | Verbindung schwarz → R1 prüfen |
| Sensor-LED reagiert nicht | falsches Metall (Alu, Kupfer), zu weit weg, Target zu klein, Sensor unversorgt | Test mit dicker Stahl-Schraube direkt auf Sensorfläche; 12 V zwischen braun/blau messen |
| Sensor-LED leuchtet, A0 trotzdem auf 5 V | Signal-Strecke (schwarz → R1 → A0) unterbrochen | Durchgang prüfen, Lötstelle nachsehen |
| Wert flackert / springt | Motor-EMV ohne Filter | 47 nF Filter-C nachrüsten, Twisted Pair Sensor↔Teiler |
| Sensor löst immer aus (auch ohne Metall) | Fremdmetall in der Nähe (Schraube, Spindel, Rahmen) | Sensor freistellen, ≥ 3× Sn Abstand zu Fremdmetall |
| 11,6 V statt 12 V auf schwarz | normal! NPN-Sensor in Idle gibt V_S minus 0,4 V aus | kein Defekt, vor dem Teiler ist das richtig |

---

## 4. A4988 Schrittmotor-Treiber (NEMA 17)

```
                  ┌───────────────────────┐
       12 V ────► │ V_MOT          1B │───┐
                  │              ↓   1A │   ├─► NEMA 17 Spule A
                  │            ╔═════╗  │   │
                  │            ║  IC ║  │   ├─► NEMA 17 Spule B
                  │            ╚═════╝  │   │
                  │                2A │───┘
                  │                2B │
       Nano D2 ─► │ STEP                │
       Nano D3 ─► │ DIR                 │
       Nano D4 ─► │ EN  (LOW = aktiv)   │
                  │ MS1/MS2/MS3 ► offen │  ← Vollschritt; ggf. überbrücken für 1/8 oder 1/16
                  │ RESET ─┐            │
                  │ SLEEP ─┤  verbinden │  ← per Kabelbrücke beide HIGH
                  │        └─ V_DD 5 V  │
                  │ V_DD ───────────── │ ◄── 5 V Logik
                  │ GND_logic ──────── │ ◄── GND_LOGIC zum Sternpunkt
                  │ GND_motor ──────── │ ◄── GND_MOTOR zum Sternpunkt
                  └───────────────────────┘
                         │
                       ║ ║  100 µF / ≥ 25 V Elko (low ESR)
                       ║ ║  zwischen V_MOT + GND_motor
                       ─ ─  PFLICHT, < 5 cm vom IC
                        │
                       GND
```

### ★ Beide GND-Pins extern anschließen (kritisch!) ★

Der A4988-Carrier hat **zwei separate GND-Pins** — einen neben V_MOT (Motor-GND) und einen neben V_DD (Logik-GND). Sie sind intern auf der Platine verbunden, aber **nur über einen schmalen Leiterzug**.

| Pfad | Strom | Wenn nur EIN GND extern angeschlossen |
|---|---|---|
| Motor-Spule → GND_motor | bis 1,5 A peak | OK |
| Logik (DIR/STEP/EN) → GND_logic | < 10 mA | OK |
| **Beide Ströme über die interne Brücke** | 1,5 A + Spikes | ❌ Spannungsabfall ~75 mV → "Ground Bounce" → verlorene Steps oder zappelnder Stepper |

→ **Beide GND-Pins per separatem Draht zum Sternpunkt führen.** Mehraufwand: ein zusätzliches Kabelstück. Nutzen: zuverlässige Step-Erzeugung ohne EMV-Probleme.

### Twisted Pair für Versorgung

Saubere Verkabelung zum Sternpunkt:

```
   Verdrillt:    ●── 12 V ──┐
                 ●── GND_motor ──┘   → an A4988 V_MOT + GND_motor

   Verdrillt:    ●── 5 V  ──┐
                 ●── GND_logic ──┘   → an A4988 V_DD + GND_logic
```

Twisted Pair reduziert die Schleifenfläche → weniger ausgestrahlte EMV bei 800 Steps/Sek, weniger eingestrahlte Störung.

### Gilt das für andere Treiber auch?

| Treiber | GND-Pins | Beide extern anschließen? |
|---|---|---|
| **A4988** | GND_motor + GND_logic | ✅ ja, beide |
| DRV8825 | GND_motor + GND_logic | ✅ ja, beide |
| TMC2208 / TMC2209 | GND_motor + GND_logic | ✅ ja, beide |
| **L298N** (Standard-Modul) | 1 GND-Schraubklemme | nur eine, intern simpler aufgebaut |
| TB6612FNG | GND × 4 (alle gleich) | mindestens 2, idealerweise alle |

Bei allen "Logic + Power"-Treibern ist die Trennung kritisch.

### Elko-Spezifikation am A4988

| Parameter | Wert | Begründung |
|---|---|---|
| **Kapazität** | **≥ 100 µF** (220 µF besser, bis 470 µF sinnvoll) | Datenblatt-Minimum; mehr puffert besser |
| **Spannung** | **≥ 25 V** | 12 V Betriebsspannung, Spikes bis 25 V beim Schalten — 16 V Elko ist **zu knapp** und stirbt |
| **Typ** | Low ESR (z. B. Panasonic FC, Nichicon PW, Rubycon ZL) | A4988 schaltet intern mit 500 kHz, Standard-Elkos haben hier zu hohen ESR |
| **Temperatur** | 105 °C | nicht 85 °C — der A4988 wird im Betrieb warm |
| **Position** | < 5 cm vom V_MOT-Pin, **direkt auf den Treiber-Header** löten | Drahtinduktivität würde sonst die Filterwirkung neutralisieren |

> ⚠️ **16 V-Elko bei 12 V V_MOT:** **NICHT verwenden**. Headroom nur 33 %, beim
> ersten Step-Spike geht der Elko stilistisch zwischen Plopp (leise) und
> Knall (laut) ins Nirwana und nimmt den A4988 mit. Mindestens 25 V ist Pflicht.

### Vref einstellen (vor erstem Anlauf!)

```
Vref-Poti am A4988 mit Multimeter messen (zwischen Poti-Mittenkontakt und GND)
Ziel: Vref = 0,7 ... 1,0 V

Strom pro Spule = Vref / (8 · R_sense)
NEMA 17 (1,5 A nominal): Vref ≈ 0,8 V → I ≈ 1,0 A
```

> **Sicherheits-Reihenfolge:** Erst Vref justieren, dann V_MOT 12 V einschalten,
> dann erst Logik 5 V. Sonst stirbt der Treiber.

---

## 5. L298N Standard-Modul (großes Board mit Kühlkörper + ENA/ENB)

> Großes Modul mit Schraubklemmen für Motor/Power und Pin-Header für die
> Logik-Eingänge. ENA/ENB erlauben echte Drehzahl-Regelung in **beide**
> Richtungen. Dicke Litze passt direkt in die Schraubklemmen.

```
              ┌──────────────────────────────────┐
   12 V ════► │ +12 V (Schraubkl.)     Out 1 │═══► DC-Motor Presse +
              │                        Out 2 │═══► DC-Motor Presse −
              │                        Out 3 │═══► DC-Motor Pusher +
              │                        Out 4 │═══► DC-Motor Pusher −
              │                                  │
   D5 ──────► │ ENA   (PWM Timer0, Presse Drehz.) │
   D6 ──────► │ ENB   (PWM Timer0, Pusher Drehz.) │
   D7 ──────► │ IN1   (Presse Richtung A)        │
   D8 ──────► │ IN2   (Presse Richtung B)        │
   D9 ──────► │ IN3   (Pusher Richtung A)        │
   D10 ─────► │ IN4   (Pusher Richtung B)        │
              │                                  │
              │ +5 V ◄── Jumper "5V_EN" stecken  │  (interner Regler, wenn V_S = 12 V)
              │ GND (Schraubkl.) ─────────────── │ ◄── GND Sternpunkt
              └──────────────────────────────────┘
                       │
                     ║ ║  470 µF / ≥ 25 V Elko
                     ║ ║  (1000 µF besser, low ESR optional)
                     ─ ─  an der +12 V-Schraubklemme
                      │
                     GND

   ══►  = Schraubklemme (dicke Litze 0,5–0,75 mm²)
   ──►  = Pin-Header (dünne Dupont/Litze, Logik-Signal)
```

> **Jumper "5V_EN":** bei V_S = 12 V stecken lassen (interner 78M05 erzeugt 5 V
> Logik). Bei V_S > 12 V abziehen und 5 V extern einspeisen. Die 5 V vom L298N
> **NICHT** für Servo/Pi nutzen — bricht unter Motorlast ein.

### Elko-Spezifikation am L298N

| Parameter | Wert | Begründung |
|---|---|---|
| **Kapazität** | **≥ 470 µF** (1000 µF empfohlen) | DC-Motoren ziehen 3–5× Nennstrom beim Anfahren — Elko liefert die Spitze |
| **Spannung** | **≥ 25 V** | Drehrichtungswechsel + Bürstenfunken können > 18 V Spikes erzeugen |
| **Typ** | Standard-Elko reicht (PWM nur ~490 Hz) | Low ESR ist nice-to-have, nicht Pflicht wie beim A4988 |
| **Temperatur** | 105 °C | Standard, nicht die billigen 85 °C-Typen |
| **Position** | < 5 cm vom V_S-Pin am Modul | Drahtinduktivität reduzieren |

> Auf vielen L298N-Modulen ist schon ein **kleiner Elko** (z. B. 47 µF/25 V)
> aufgelötet — der reicht NICHT als alleiniger Puffer. Externen 470–1000 µF
> **parallel** dazu, an der +12 V-Schraubklemme.

### Optional: Externe Flyback-Dioden

Der L298N-Chip hat **interne** Freilaufdioden, die aber langsam sind (Recovery ~1–2 µs). Viele Module sparen die externen Schottkys ein. Nachrüsten verlängert die Lebensdauer:

```
              Out1 ●────●────────● DC-Motor +
                       │
                      ─┴─ Schottky      Kathode an +12 V
                       ▲                Anode an Motor-Klemme
                      ─┬─
                       │
              Out2 ●────●────────● DC-Motor −

   Pro Motor: 4× Dioden (eine an jede der vier Brücken-Kombinationen).
   2 Motoren = 8× Dioden total.
```

**Welche Dioden gehen?**

| Diode | I_F | V_R | V_F | Eignung als Flyback |
|---|---|---|---|---|
| **1N5819** ← Standard | 1 A | 40 V | 0,45 V | ✅ Schottky, ideal, ~5 ct/Stück |
| **1N4001–4007** | 1 A | 50–1000 V | 1,0 V | ✅ Standard-Silizium, geht problemlos |
| 1N5400–5408 | 3 A | 50–1000 V | 1,0 V | ✅ überdimensioniert, super |
| **SS14** (SMD) | 1 A | 40 V | 0,5 V | ✅ Schottky-SMD, wie 1N5819 |
| MUR120 / FR107 | 1 A | 100 V | 1,0 V | ✅ Fast Recovery, klasse |
| **1N4148** | **0,2 A** | 100 V | 0,7 V | ❌ **NICHT verwenden!** Nur 200 mA Dauerstrom — brennt durch |

> ⚠️ **1N4148 ist eine Kleinsignal-Schaltdiode** für Logik-Pegel, kein
> Leistungsbauteil. Bei 1,5 A Motorstrom wird sie in Sekunden zu heiß und
> stirbt — entweder offen (kein Schutz mehr) oder kurzgeschlossen
> (Out-Pin an +12 V → L298N stirbt mit). Ungeeignet.

**Einschätzung:** für Test-Phase (Phase 1–6 Inbetriebnahme) reichen die
internen L298N-Dioden. Für Dauerbetrieb 1N5819 (oder 1N4001–4007) nachrüsten.

### Wahrheitstabelle (mit ENA/ENB)

| INx | INy | ENx (PWM) | Verhalten |
|---|---|---|---|
| HIGH | LOW | > 0 | Motor vorwärts (`fwd`) mit Drehzahl |
| LOW | HIGH | > 0 | Motor rückwärts (`rev`) mit Drehzahl |
| LOW | LOW | beliebig | Motor frei (Coast) |
| HIGH | HIGH | beliebig | Motor gebremst (Brake) |
| beliebig | beliebig | 0 | Motor aus (PWM-Stop) |

> **Vorteil ggü. Mini-Modul:** Drehzahl-Regelung in **beide** Richtungen (ENA/ENB
> PWM unabhängig von der Richtungslogik), echtes Coast (Freilauf) möglich.

> ⚠️ **Timer-Konflikt — ENA/ENB MÜSSEN auf D5/D6:**
> Die Standard-`Servo.h` belegt auf dem ATmega328 **Timer1** und deaktiviert
> damit `analogWrite()` (PWM) auf **D9 und D10** — offiziell dokumentiertes
> Arduino-Verhalten. Würde man ENA/ENB auf D9/D10 legen (wie es der ursprüngliche
> Starter tat), wäre die Drehzahl-Regelung **tot** (Motor liefe voll oder gar
> nicht).
>
> **Lösung in diesem Projekt:** ENA/ENB liegen auf **D5/D6 (Timer0-PWM)** —
> davon unbeeinflusst. Die IN-Pins (D7–D10) sind reine **digitale**
> Richtungspins; dass Servo.h auf D9/D10 das PWM killt, ist hier egal, weil
> dort kein PWM gebraucht wird. Kein Library-Wechsel nötig.
>
> Timer0-PWM läuft mit ~976 Hz (statt 490 Hz) — für DC-Motor-Drehzahl sogar
> besser (weniger hörbares Pfeifen). `millis()`/`delay()` bleiben funktionsfähig.

---

## 6. Servo-Entkopplung

```
                              ╔═══════════════╗
   Buck 5 V ──────●──────────╣ VCC (rot)     ║
                  │           ║               ║
                ║ ║           ║   SG90 Servo  ║
                ║ ║ 470 µF    ║  (Hülsenschieber)║
                ─ ─ ≥ 10 V    ║               ║
                  │           ║               ║
   GND ───────────●──────────╣ GND (braun)   ║
                              ║               ║
   Nano D11 ─────────────────╣ Signal (orange)║
                              ╚═══════════════╝
```

### Elko-Spezifikation am Servo

| Parameter | Wert | Begründung |
|---|---|---|
| **Kapazität** | **≥ 470 µF** (bis 2200 µF unproblematisch) | Servo-Anlaufstrom 0,5–1 A für ~5 ms |
| **Spannung** | **≥ 10 V** (16 V oder 25 V auch fein) | 5 V Servoversorgung, Spikes klein — 10 V genügt |
| **Typ** | Standard-Elko, kein Low ESR nötig | Servo zieht nur kurze Strompulse, keine hochfrequente Schaltlast |
| **Position** | < 3 cm vom Servo-VCC-Pin, **NICHT** am Buck | Leitungsinduktivität würde die lokale Pufferwirkung neutralisieren |

> Der **Elko direkt am Servo** (nicht erst am Buck) ist entscheidend — die kurze
> Stromspitze beim Servo-Anlauf bricht sonst die 5 V-Schiene ein und der Pi
> bootet neu.

> **Bonus:** Mit 1000+ µF am Servo brauchst du keinen separaten Bulk-Cap am
> Buck-Ausgang — der Servo-Elko puffert die ganze 5 V-Schiene mit, falls Pi
> und Servo räumlich nahe beieinander liegen.

### Wenn Elko nicht direkt am Servo sitzen kann (langes Kabel)

Wenn zwischen Buck/Verteiler und Servo ein längeres Kabel liegt und der große Elko dort verbleiben muss: **Zwei-Kondensator-Strategie**.

```
   Buck 5 V ───●────[langes Kabel]────●─── Servo VCC
               │                      │
             ║ ║ großer Elko        ║ ║ kleiner Elko
             ║ ║ (2200 µF)          ║ ║ 220–470 µF
             ─ ─ bleibt am Buck     ─ ─  + 100 nF Keramik
               │                      │   DIREKT am Servo-Stecker
   GND ────────●──────────────────────●─── Servo GND
```

| Kondensator | Wert | Position | Aufgabe |
|---|---|---|---|
| **Bulk** | 470–2200 µF | wo's passt (Buck/WAGO) | langsame Energie, Gesamt-Puffer |
| **Lokal** | 220–470 µF + 100 nF Keramik | **direkt am Servo-Stecker** | fängt schnelle Anlaufspitze ab |

Den **kleinen lokalen Elko** an die Servo-eigene Pigtail-Litze löten (rot=VCC, braun=GND, am Stecker-Ende) — Kostet ~10 ct, macht die Kabellänge praktisch egal.

**Faustwerte Spannungsabfall** bei 1 A Servo-Anlauf:

| Kabellänge hin+zurück | 0,5 mm² | 0,25 mm² |
|---|---|---|
| 20 cm | 7 mV | 14 mV | ✅ unkritisch |
| 50 cm | 17 mV | 34 mV | ✅ ok |
| 1 m | 34 mV | 68 mV | ⚠️ spürbar |
| 2 m | 68 mV | 136 mV | ❌ Servo zittert |

→ Ab ~50 cm Kabellänge zum Servo: lokalen kleinen Elko **immer** einbauen.

---

## 7. Manueller Start-Taster — entfällt

Die Steuerung erfolgt **komplett remote** über den Raspberry Pi (HTTP-API,
später BLE). Es gibt **keinen physischen Start-Taster** am Nano.

Der Pin **D12** ist deshalb für den **Hülsenmagazin-Motor** umgewidmet (siehe § 10).

> Falls du später trotzdem einen Hardware-Schalter willst (z. B. Notaus-mäßig): den
> Pi-seitig per GPIO einlesen, nicht den Nano-Pin opfern.

---

## 8. Notaus + Sicherungen (Hardware-seitig, geplant)

```mermaid
flowchart LR
    PSU["12 V Netzteil"] --> F1["F1<br/>5 A T<br/>Hauptsicherung"]
    F1 --> SW["Pilzkopf<br/>NOTAUS<br/>Oeffner-Kontakt"]
    SW -->|12 V Motor-Schiene| LOAD["L298N + A4988<br/>+ Initiatoren ueber F3"]

    F1 -.->|12 V Logik-Schiene<br/>wird NICHT unterbrochen| F2["F2<br/>1 A T"]
    F2 --> BUCK["Buck-Konverter<br/>5 V Pi/Servo/Nano"]
    BUCK --> NANO["Nano detektiert<br/>via Watchdog-Timeout<br/>oder dedizierten GPIO"]

    classDef warn fill:#ffcccc,stroke:#cc0000,stroke-width:2px;
    classDef fuse fill:#ffe0e0,stroke:#cc0000,stroke-width:2px;
    class SW warn;
    class F1,F2 fuse;
```

### Reihenfolge der Schutzelemente

```
PSU ──► [F1 Hauptsicherung] ──┬──► [NOTAUS-Schalter] ──► Motor-12V (L298N, A4988, F3→Initiatoren)
                              │
                              └──► [F2] ──► Buck → 5V (Pi, Servo, Nano-Logik)
```

| Element | Schützt gegen | Was passiert beim Auslösen |
|---|---|---|
| **F1** | Kurzschluss / Defekt irgendwo im 12 V-Bus | Maschine **komplett** stromlos (auch Pi) |
| **NOTAUS** | bewusst durch Bediener | nur Motorseite stromlos; Pi/Nano laufen weiter, melden Notaus-Zustand |
| **F2** | Kurzschluss im Buck oder Pi/Servo/Nano | Logikseite aus, Motorseite läuft theoretisch weiter — aber Watchdog im Nano triggert nach 5 s "alle Motoren aus", weil der Pi nicht mehr antwortet |
| **F3** | Verdrahtungsfehler an Initiatoren (z. B. 12 V auf Signal-Eingang) | Sensoren tot, Stopfsequenz pausiert; Motoren bleiben an, müssen vom Pi kontrolliert gestoppt werden |

> Wichtig: Notaus unterbricht **nur die 12 V-Motorschiene**, nicht die 5 V-Logik.
> So bleibt der Pi an, kann den Notaus-Zustand loggen und die App informieren.
> Der Nano merkt am Wegfall der INIT-Signale (12 V weg) bzw. am Watchdog (5 s
> kein Pi-Befehl wird ohnehin ausgewertet).
>
> **F1 sitzt VOR dem Notaus**, damit auch bei verschweißtem Notaus-Kontakt
> (Worst Case) noch ein Schutz greift.

---

## 9. Tabak-Dosierung (nur 2 Solenoide — KEIN Servo)

Mechanismus aus Fraens' **vollautomatischer** Maschine (nicht zu verwechseln mit
der Förderschnecke der teil-automatischen Variante). **Zwei Solenoide** dosieren
Tabak per Schwerkraft + Impuls — kein bewegtes Element dazwischen.

> **Hinweis:** Frühere Versionen dieser Doku zeigten eine zusätzliche Servo-Tilt-
> Wand. Die wurde durch die Doppel-Solenoid-Lösung ersetzt — der einzige Servo
> im Aufbau ist der Hülsen-Schieber (D11). A3 ist frei (Reserve).

### Funktionsprinzip

```
              ╔════════════════════════════════╗
              ║   Tabakvorrat (Acryl-Trog)     ║
              ║                                ║
   ●═══════→  ║  ║║║   ║║║   ║║║   ║║║         ║   ← Hubmagnet #1 (Front-Knock)
   "Front-    ║                                ║     pulst seitlich gegen Trog-Wand
   Schlag"    ║                                ║     bricht Tabak-Brücken
              ║                                ║
              ╚═════════╤══════════════════════╝
                        │ Tabak rieselt durch Schwerkraft
                        │ (kein bewegtes Element nötig)
                        │
                  ●═════→ Hubmagnet #2 (Top-Druck)
                  "Top-Schlag"   pulst von oben → drückt Tabak in Stopfrohr
                                  = Part-83_Ausgefahren im STEP
                        │
                        ▼
                  Stopfrohr / Press-Kammer

   Beide Solenoide pulsen SYNCHRON, 8× pro Dose (siehe Knock-Sequenz).
```

### Komponenten

| Bauteil | Spec | Aufgabe |
|---|---|---|
| **Hubmagnet #1** | Heschen HS-0530B, 12 V, 5 mm Hub, 3–5 N, 0,5 A | seitliches Klopfen am Vorratstrog |
| **Hubmagnet #2** | Heschen HS-0530B (identisch) | Drücken von oben |
| **2× IRLZ44N MOSFET** | Logic-Level, Rds_on ~17 mΩ, 30+ A | je ein Treiber pro Solenoid (statt L298N-Mini) |
| **2× 1N5819 Flyback** | Schottky, 1 A | absorbieren Back-EMF beim Abschalten — Pflicht bei induktiven Lasten |
| 2× 100 Ω Gate-Widerstand | – | dämpfen Gate-Switching, schützen Nano-Pin |

> **Warum nicht L298N-Mini?** Ursprünglich geplant, aber bei Heschen-Halteströmen
> (~1 A pro Solenoid) und 2,5 V internem Drop am L298N entstehen 2,5 W pro Kanal
> = 5 W bei beiden aktiv — Mini-Modul ohne Kühlkörper überhitzt. MOSFET hat
> < 20 mV Drop, virtuell keine Wärme, und Solenoid sieht volle 12 V.

### Verkabelung MOSFET → Solenoid (pro Solenoid identisch)

```
   12 V Bus (über F4) ──●────[Solenoid Heschen HS-0530B]────●
                        │                                   │
                        │ Kathode                           │ Drain
                        ▼                                   │
                    ─┤├─ 1N5819 Flyback                     │
                        │ (Anode an Drain,                  │
                        │  Kathode an +12 V)                │
                        │                                   │
                        ●───────────────────────────────────●
                                                            │
                                                          ──┴── MOSFET
                                                          │     IRLZ44N
   Nano A4 (oder D13) ──[100 Ω]─── Gate ─────────────────┤├── (Logic-Level,
                                                          │     30 A, ~17 mΩ)
                                                            │ Source
                                                            ●
                                                            │
   GND (Sternpunkt) ────────────────────────────────────────●
```

**Steuerlogik pro Solenoid:**

| Nano-Pin | MOSFET-Gate | Solenoid-Zustand |
|---|---|---|
| HIGH (5 V) | öffnet (Source-Drain leitet) | EIN — 12 V über Spule |
| LOW (0 V) | sperrt | AUS — Strom 0 |

### Spannungs-Realität (MOSFET vs. L298N — warum gewechselt)

| | L298N Mini (verworfen) | MOSFET (jetzt) |
|---|---|---|
| Spannungsabfall bei 1 A | ~2,5 V | ~17 mV |
| Solenoid sieht | ~9,5 V → 63 % Nennkraft | volle 12 V → 100 % |
| Verlustleistung pro Kanal | ~2,5 W | ~17 mW |
| Dauer-Halten möglich? | ❌ überhitzt | ✅ kalt |
| Pins am Nano | 2 (oder 4 ohne Hardwire) | 1 pro Solenoid |

### Sicherung F4 (zusätzlich zu F1/F2/F3)

```
12 V-Bus ──[F4: 1 A T]──► Solenoid-Stromschiene (beide Solenoide via MOSFET)
```

| Position | Wert | Begründung |
|---|---|---|
| **F4 Solenoid-Zweig** | 1 A T | 2× ~1 A Halteströme bei gleichzeitigem Pulse → träge, 5×20 mm |

Trennt den Tabak-Dosier-Zweig vom Rest des 12-V-Busses — wenn ein Solenoid mal
kurzschließt (Coil durchgeschmort), bleibt der Rest der Maschine in Betrieb.

### Steuerlogik (implementiert in Firmware v0.2)

Knock-Sequenz: beide Solenoide pulsen **synchron**, kein Servo.

```cpp
void runKnock(uint8_t cycles) {
    if (cycles == 0) cycles = KNOCK_CYCLES_DEFAULT;
    for (uint8_t i = 0; i < cycles; i++) {
        digitalWrite(PIN_SOLENOID_1, HIGH);
        digitalWrite(PIN_SOLENOID_2, HIGH);
        delay(KNOCK_PULSE_ON_MS);     // 80 ms

        digitalWrite(PIN_SOLENOID_1, LOW);
        digitalWrite(PIN_SOLENOID_2, LOW);
        delay(KNOCK_PULSE_OFF_MS);    // 120 ms (Erholung)

        lastCommandMs = millis();      // Watchdog füttern
    }
}
```

Default-Parameter (in `config.h`):
- `KNOCK_PULSE_ON_MS = 80`  (Solenoid an)
- `KNOCK_PULSE_OFF_MS = 120` (Pause — Heschen sind nicht für 100 % Duty cycle ausgelegt)
- `KNOCK_CYCLES_DEFAULT = 8` (analog zu Fraens' Default)

Gesamt-Dauer: 8 × 200 ms = **1,6 Sekunden** pro Knock-Befehl — unter Watchdog-Timeout (5 s).

### Duty-Cycle-Warnung

Heschen HS-0530B sind **intermittierende Solenoide** — nicht für Dauer-ON ausgelegt:

| Duty Cycle | Wirkung |
|---|---|
| < 30 % | sicher, dauerhaft betreibbar |
| 30–50 % | erlaubt, leicht warm |
| > 50 % oder Dauer-ON | Coil überhitzt, Magnet versagt thermisch |

→ Standard-Knock-Pattern (80 ms on / 120 ms off = **40 % Duty**, 8× in 1,6 s, dann lange Pause) ist unkritisch.

> **NIE** den Solenoid „testweise" für mehrere Sekunden HIGH halten — er wird heiß
> und kann durchbrennen. Maximaler Einzelpuls < 1 Sekunde. In der Firmware
> erzwungen via `SOLENOID_PULSE_MAX_MS = 1000` in `config.h`.

---

## 10. Hülsenmagazin-Motor (5 V, ~40 mA, MOSFET-getrieben)

Kleiner Vibrations-/DC-Motor zum Vorrücken der Hülsen im Magazin. Wird vom Pi
remote getriggert (`hopper on/off/run <ms>`) — typisch beim Eject einer fertigen
Zigarette, um die nächste Hülse in Position zu rütteln.

### Verkabelung

```
   5 V Bus ──●────[Hülsen-Motor 5 V / 40 mA]────●
             │                                  │
             │ Kathode                          │ Drain
             ▼                                  │
         ─┤├─ 1N4148 Flyback                    │
             │ (40 mA passt — 1N4148 verträgt   │
             │  200 mA Dauerstrom)              │
             │                                  │
             ●──────────────────────────────────●
                                                │
                                              ──┴── MOSFET
                                              │     2N7000 (TO-92, klein)
   Nano D12 ──[1 kΩ]── Gate ─────────────────┤├──  ODER IRLZ44N (overkill, ok)
                                              │
                                                │ Source
                                                ●
                                                │
   GND ─────────────────────────────────────────●
```

> **Warum 1 kΩ statt 100 Ω** wie bei Solenoiden? Bei 40 mA und langsamem
> Schalten ist die Gate-Ladung minimal — höherer Series-Widerstand reicht und
> bremst die Schaltflanke leicht ab (weniger EMV-Spitzen).

### Warum Treiber statt direkt Nano-Pin?

| | Direkt Nano D12 → Motor | MOSFET-Treiber |
|---|---|---|
| Pin-Belastung | 40 mA = exakt am Limit (max 40 mA/Pin) | 0 mA — Pin liefert nur Gate-Ladung |
| Anlaufspitze | kurzfristig > 40 mA → Pin gefährdet | irrelevant |
| Back-EMF beim Abschalten | Pin-Schutzdiode wird gefordert | externer Flyback fängt es ab |
| Lebensdauer | über Zeit kann Pin sterben | unbegrenzt |

→ MOSFET kostet 10 ct (2N7000) und schützt den Nano dauerhaft. Lohnt sich.

### Stromversorgung

5 V kommt vom **Buck-Konverter-Ausgang** (gleiche 5 V-Schiene wie Pi und
Servo), **nicht** vom Nano-5V-Pin. Der Nano-Regler ist klein (max ~500 mA), den
Buck-Bus belasten ist sauberer.

### Firmware-Befehle

```
hopper on              → Motor an (läuft bis off, stop oder Watchdog)
hopper off             → Motor aus
hopper run <ms>        → Motor für N ms an (max 4000 ms wegen Watchdog), dann aus
```

Default-Laufzeit: `HOPPER_DEFAULT_MS = 1500` (1,5 s — typisch ausreichend, um
eine Hülse vorzurücken).

---

## Verwandte Dokumente

- [`pinout.md`](pinout.md) — vollständige Pin-zu-Bauteil-Tabelle
- [`protocol.md`](protocol.md) — Serial-Befehle Pi ↔ Nano
- [`../CLAUDE.md`](../CLAUDE.md) — Projektkontext & Materialliste
- [`../firmware/nano/src/pins.h`](../firmware/nano/src/pins.h) — Pin-Defines im Code

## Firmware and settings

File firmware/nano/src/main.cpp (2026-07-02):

// =====================================================
// main.cpp
// Stopfmaschine - Arduino Nano Firmware v0.3.0
//
// Architektur:
//   - Live-tunbare Parameter im EEPROM (params.h/cpp)
//   - Kooperative State-Machine (home / stuff / step / idle / error)
//   - Background-Hopper-Cycle parallel zur Hauptsequenz
//   - Alle Sequenz-Befehle non-blocking — `stop` greift sofort
//
// Befehle (115200 Baud):
//   help                     - Liste
//   ping                     - "pong"
//   status                   - state + sensoren + aktoren als key=value
//   params                   - alle EEPROM-Parameter
//   get <key>                - einzelner Parameter
//   set <key> <value>        - Parameter setzen (validiert + persistiert)
//   home                     - Referenzfahrt (Trommel → Lichtschranke, Pusher → A2)
//   stuff                    - Vollsequenz, läuft endlos bis `stop`
//   step <n>                 - Einzelschritt (1..11 = Stuff-Steps)
//   stop                     - Notaus, alles aus, Mode → IDLE
//
//   --- Manual (nur erlaubt wenn state=idle) ---
//   stepper <steps>          - relative Stepper-Bewegung
//   press fwd|rev|stop       - DC-Motor Presse (PWM aus params.press_pwm)
//   pusher fwd|rev|stop      - DC-Motor Pusher (PWM aus params.pusher_pwm)
//   servo <0..180>           - Hülsen-Schieber-Servo
//   solenoid 1|2 off|pulse <ms>   (Dauer-ON deaktiviert — Magnet-Schutz)
//   hopper on|off|test <ms>  - on = Background-Cycle, test = einmaliger Run
//   knock [<cycles>]         - läuft als Step (kann via stop abgebrochen werden)
// =====================================================

#include <Arduino.h>
#include <AccelStepper.h>
#include <Servo.h>
#include "pins.h"
#include "config.h"
#include "params.h"

// --- Hardware ---
AccelStepper stepper(AccelStepper::DRIVER, PIN_STEPPER_STEP, PIN_STEPPER_DIR);
Servo        tubeServo;

// --- Watchdog ---
unsigned long lastCommandMs = 0;
bool          watchdogTripped = false;

// --- State-Machine ---
enum Mode : uint8_t {
    MODE_IDLE     = 0,
    MODE_HOMING   = 1,
    MODE_STUFFING = 2,
    MODE_STEP     = 3,
    MODE_ERROR    = 4
};

// Stuff steps 1..11, Home steps 101..104
constexpr uint8_t STEP_DRUM       = 1;
constexpr uint8_t STEP_SERVO_LOAD = 2;
constexpr uint8_t STEP_SERVO_HOME = 3;
constexpr uint8_t STEP_KNOCK      = 4;
constexpr uint8_t STEP_PRESS_FWD  = 5;
constexpr uint8_t STEP_PRESS_REV  = 6;
constexpr uint8_t STEP_PUSH_FWD   = 7;
constexpr uint8_t STEP_PUSH_REV   = 8;
constexpr uint8_t STEP_EJECT_FWD  = 9;   // Kippe vom Stutzen drücken (zeitgesteuert)
constexpr uint8_t STEP_EJECT_REV  = 10;  // wieder zurück bis A2
constexpr uint8_t STEP_DELAY      = 11;
constexpr uint8_t STUFF_STEP_MIN  = 1;
constexpr uint8_t STUFF_STEP_MAX  = 11;

constexpr uint8_t HOME_DRUM      = 101;
constexpr uint8_t HOME_PUSH_REV  = 102;
constexpr uint8_t HOME_SERVO     = 103;
constexpr uint8_t HOME_PRESS_REV = 104;
constexpr uint8_t HOME_DONE      = 105;

Mode          currentMode    = MODE_IDLE;
uint8_t       currentStep    = 0;
unsigned long stepStartedMs  = 0;
char          errorMsg[24]   = "";

// Knock-Sub-State (innerhalb STEP_KNOCK)
uint8_t       knockCounter      = 0;
bool          knockPhaseOn      = false;
unsigned long knockPhaseStartMs = 0;
uint8_t       knockTargetCycles = 0;  // für Manual-Knock mit eigener Cycle-Zahl

// Hopper-Background
bool          hopperEnabled      = false;
unsigned long hopperCycleStartMs = 0;
unsigned long hopperManualUntil  = 0;  // für `hopper test <ms>` (Manual)

// =====================================================
// Hardware-Helpers
// =====================================================

static void allMotorsOff() {
    digitalWrite(PIN_STEPPER_EN, HIGH);
    digitalWrite(PIN_PRESS_IN1, LOW);
    digitalWrite(PIN_PRESS_IN2, LOW);
    digitalWrite(PIN_PUSHER_IN3, LOW);
    digitalWrite(PIN_PUSHER_IN4, LOW);
    analogWrite(PIN_PRESS_ENA, 0);
    analogWrite(PIN_PUSHER_ENB, 0);
    digitalWrite(PIN_SOLENOID_1, LOW);
    digitalWrite(PIN_SOLENOID_2, LOW);
    digitalWrite(PIN_HOPPER_MOTOR, LOW);
}

static void enableStepper() { digitalWrite(PIN_STEPPER_EN, LOW); }

static void pressDrive(const char* dir) {
    if (strcmp(dir, "fwd") == 0) {
        digitalWrite(PIN_PRESS_IN1, HIGH);
        digitalWrite(PIN_PRESS_IN2, LOW);
        analogWrite(PIN_PRESS_ENA, params.press_pwm);
    } else if (strcmp(dir, "rev") == 0) {
        digitalWrite(PIN_PRESS_IN1, LOW);
        digitalWrite(PIN_PRESS_IN2, HIGH);
        analogWrite(PIN_PRESS_ENA, params.press_pwm);
    } else {
        digitalWrite(PIN_PRESS_IN1, LOW);
        digitalWrite(PIN_PRESS_IN2, LOW);
        analogWrite(PIN_PRESS_ENA, 0);
    }
}

static void pusherDrive(const char* dir) {
    if (strcmp(dir, "fwd") == 0) {
        digitalWrite(PIN_PUSHER_IN3, HIGH);
        digitalWrite(PIN_PUSHER_IN4, LOW);
        analogWrite(PIN_PUSHER_ENB, params.pusher_pwm);
    } else if (strcmp(dir, "rev") == 0) {
        digitalWrite(PIN_PUSHER_IN3, LOW);
        digitalWrite(PIN_PUSHER_IN4, HIGH);
        analogWrite(PIN_PUSHER_ENB, params.pusher_pwm);
    } else {
        digitalWrite(PIN_PUSHER_IN3, LOW);
        digitalWrite(PIN_PUSHER_IN4, LOW);
        analogWrite(PIN_PUSHER_ENB, 0);
    }
}

// =====================================================
// State-Machine
// =====================================================

static void setError(const char* msg) {
    strncpy(errorMsg, msg, sizeof(errorMsg) - 1);
    errorMsg[sizeof(errorMsg) - 1] = '\0';
    currentMode = MODE_ERROR;
    allMotorsOff();
    hopperEnabled = false;
    Serial.print(F("err sequence:")); Serial.println(errorMsg);
}

static void clearError() { errorMsg[0] = '\0'; }

static void enterStep(uint8_t step);

static void advanceStep() {
    if (currentMode == MODE_STEP) {
        // Einzelschritt fertig → zurück zu IDLE
        currentMode = MODE_IDLE;
        currentStep = 0;
        return;
    }
    if (currentMode == MODE_STUFFING) {
        uint8_t next = currentStep + 1;
        if (next > STUFF_STEP_MAX) next = STUFF_STEP_MIN;
        enterStep(next);
        return;
    }
    if (currentMode == MODE_HOMING) {
        switch (currentStep) {
            case HOME_DRUM:      enterStep(HOME_PUSH_REV);  break;
            case HOME_PUSH_REV:  enterStep(HOME_SERVO);     break;
            case HOME_SERVO:     enterStep(HOME_PRESS_REV); break;
            case HOME_PRESS_REV:
                currentMode = MODE_IDLE;
                currentStep = 0;
                Serial.println(F("ok home_done"));
                break;
        }
    }
}

static void enterStep(uint8_t step) {
    currentStep   = step;
    stepStartedMs = millis();

    switch (step) {
        // ----- Stuff steps -----
        case STEP_DRUM:
            enableStepper();
            stepper.setMaxSpeed(STEPPER_MAX_SPEED);
            stepper.move(params.drum_steps_per_pos);
            break;

        case STEP_SERVO_LOAD:
            tubeServo.write(params.servo_load);
            break;

        case STEP_SERVO_HOME:
            tubeServo.write(params.servo_home);
            break;

        case STEP_KNOCK:
            knockCounter      = 0;
            knockPhaseOn      = true;
            knockPhaseStartMs = millis();
            knockTargetCycles = (knockTargetCycles > 0) ? knockTargetCycles : params.knock_cycles;
            digitalWrite(PIN_SOLENOID_1, HIGH);
            digitalWrite(PIN_SOLENOID_2, HIGH);
            break;

        case STEP_PRESS_FWD:
            pressDrive("fwd");
            break;

        case STEP_PRESS_REV:
            pressDrive("rev");
            break;

        case STEP_PUSH_FWD:
            pusherDrive("fwd");
            break;

        case STEP_PUSH_REV:
            pusherDrive("rev");
            break;

        case STEP_EJECT_FWD:
            // Pusher ist komplett hinten (aus der Kippe raus). Jetzt ein kurzer
            // Vorstoß gegen die gestopfte Zigarette: drückt sie vom Füllstutzen
            // ab und zurück in die Trommel.
            pusherDrive("fwd");
            break;

        case STEP_EJECT_REV:
            pusherDrive("rev");
            break;

        case STEP_DELAY:
            // nichts zu starten, nur warten
            break;

        // ----- Home steps -----
        case HOME_DRUM:
            enableStepper();
            stepper.setMaxSpeed(STEPPER_HOME_SPEED);
            // große Distanz in eine Richtung — wir stoppen über den Sensor
            stepper.move((long)STEPPER_STEPS_PER_REV * 4);
            break;

        case HOME_PUSH_REV:
            pusherDrive("rev");
            break;

        case HOME_SERVO:
            tubeServo.write(params.servo_home);
            break;

        case HOME_PRESS_REV:
            pressDrive("rev");
            break;
    }
}

static void tickKnock() {
    unsigned long now = millis();
    if (knockPhaseOn) {
        if (now - knockPhaseStartMs >= params.knock_on_ms) {
            digitalWrite(PIN_SOLENOID_1, LOW);
            digitalWrite(PIN_SOLENOID_2, LOW);
            knockPhaseOn      = false;
            knockPhaseStartMs = now;
        }
    } else {
        if (now - knockPhaseStartMs >= params.knock_off_ms) {
            knockCounter++;
            if (knockCounter >= knockTargetCycles) {
                knockTargetCycles = 0;  // reset für nächstes Mal
                advanceStep();
                return;
            }
            digitalWrite(PIN_SOLENOID_1, HIGH);
            digitalWrite(PIN_SOLENOID_2, HIGH);
            knockPhaseOn      = true;
            knockPhaseStartMs = now;
        }
    }
}

static void tickStep() {
    unsigned long now = millis();

    switch (currentStep) {
        case STEP_DRUM:
            if (stepper.distanceToGo() == 0) advanceStep();
            break;

        case STEP_SERVO_LOAD:
        case STEP_SERVO_HOME:
        case HOME_SERVO:
            if (now - stepStartedMs >= SERVO_MOVE_DELAY_MS) advanceStep();
            break;

        case STEP_KNOCK:
            tickKnock();
            break;

        case STEP_PRESS_FWD:
            if (digitalRead(PIN_INIT_PRESS) == INIT_TRIGGERED_LEVEL) {
                pressDrive("stop");
                advanceStep();
            } else if (now - stepStartedMs > params.press_fwd_timeout_ms) {
                pressDrive("stop");
                setError("press_fwd_timeout");
            }
            break;

        case STEP_PRESS_REV:
        case HOME_PRESS_REV: {
            unsigned long elapsed = now - stepStartedMs;
            // Sicherheits-Cap ZUERST: die zeitgesteuerte Rückfahrt darf nie länger
            // laufen als press_rev_ms + Reserve. Greift nur, wenn der normale Stopp
            // ausbleibt (verklemmter State / Fehlkonfig) → Motor aus + Fehler
            // (landet im Ereignis-Protokoll).
            if (elapsed > (unsigned long)params.press_rev_ms + PRESS_REV_SAFETY_MARGIN_MS) {
                pressDrive("stop");
                setError("press_rev_safety");
            } else if (elapsed >= params.press_rev_ms) {
                pressDrive("stop");
                advanceStep();
            }
            break;
        }

        case STEP_PUSH_FWD:
            if (digitalRead(PIN_INIT_PUSH_FRONT) == INIT_TRIGGERED_LEVEL) {
                pusherDrive("stop");
                advanceStep();
            } else if (now - stepStartedMs > params.pusher_fwd_timeout_ms) {
                pusherDrive("stop");
                setError("pusher_fwd_timeout");
            }
            break;

        case STEP_PUSH_REV:
        case STEP_EJECT_REV:
        case HOME_PUSH_REV:
            if (digitalRead(PIN_INIT_PUSH_REAR) == INIT_TRIGGERED_LEVEL) {
                pusherDrive("stop");
                advanceStep();
            } else if (now - stepStartedMs > params.pusher_rev_timeout_ms) {
                pusherDrive("stop");
                setError("pusher_rev_timeout");
            }
            break;

        case STEP_EJECT_FWD:
            // Der Vorstoß darf den Front-Sensor nie erreichen — sonst wäre der
            // Pusher wieder komplett im Stutzen (eject_fwd_ms zu lang eingestellt).
            if (digitalRead(PIN_INIT_PUSH_FRONT) == INIT_TRIGGERED_LEVEL) {
                pusherDrive("stop");
                setError("eject_overtravel");
            } else if (now - stepStartedMs >= params.eject_fwd_ms) {
                pusherDrive("stop");
                advanceStep();
            }
            break;

        case STEP_DELAY:
            if (now - stepStartedMs >= params.step_delay_ms) advanceStep();
            break;

        case HOME_DRUM:
            if (digitalRead(PIN_MAGAZIN_SENSOR) == MAGAZIN_TRIGGERED_LEVEL) {
                stepper.setCurrentPosition(0);
                stepper.move(0);
                stepper.setMaxSpeed(STEPPER_MAX_SPEED);  // zurück auf normal
                advanceStep();
            } else if (now - stepStartedMs > params.home_drum_timeout_ms) {
                stepper.move(0);
                setError("home_drum_timeout");
            }
            break;
    }
}

static void tickStateMachine() {
    if (currentMode == MODE_IDLE || currentMode == MODE_ERROR) return;
    tickStep();
    // Self-Heartbeat: solange wir arbeiten, frischen Watchdog auf.
    lastCommandMs = millis();
}

// =====================================================
// Background-Hopper-Cycle
// =====================================================

static void tickHopper() {
    unsigned long now = millis();

    // Manueller Einmal-Run hat Vorrang
    if (hopperManualUntil > 0) {
        if ((long)(now - hopperManualUntil) >= 0) {
            digitalWrite(PIN_HOPPER_MOTOR, LOW);
            hopperManualUntil = 0;
        } else {
            digitalWrite(PIN_HOPPER_MOTOR, HIGH);
        }
        return;
    }

    if (!hopperEnabled) {
        digitalWrite(PIN_HOPPER_MOTOR, LOW);
        return;
    }

    unsigned long period = (unsigned long)params.hopper_on_ms + (unsigned long)params.hopper_off_ms;
    if (period == 0) { digitalWrite(PIN_HOPPER_MOTOR, LOW); return; }
    unsigned long t = (now - hopperCycleStartMs) % period;
    bool shouldRun = (t >= params.hopper_off_ms);   // off-Phase zuerst, dann on
    digitalWrite(PIN_HOPPER_MOTOR, shouldRun ? HIGH : LOW);
}

// =====================================================
// Befehle starten
// =====================================================

static void startHome() {
    if (currentMode != MODE_IDLE && currentMode != MODE_ERROR) {
        Serial.println(F("err busy"));
        return;
    }
    clearError();
    currentMode = MODE_HOMING;
    hopperEnabled = false;
    enterStep(HOME_DRUM);
    Serial.println(F("ok homing"));
}

static void startStuff() {
    if (currentMode != MODE_IDLE && currentMode != MODE_ERROR) {
        Serial.println(F("err busy"));
        return;
    }
    clearError();
    currentMode = MODE_STUFFING;
    hopperEnabled = true;
    hopperCycleStartMs = millis();
    enterStep(STEP_DRUM);
    Serial.println(F("ok stuffing"));
}

static void startStep(uint8_t n) {
    if (currentMode != MODE_IDLE && currentMode != MODE_ERROR) {
        Serial.println(F("err busy"));
        return;
    }
    if (n < STUFF_STEP_MIN || n > STUFF_STEP_MAX) {
        Serial.print(F("err step_range:1..")); Serial.println(STUFF_STEP_MAX);
        return;
    }
    clearError();
    currentMode = MODE_STEP;
    enterStep(n);
    Serial.print(F("ok step=")); Serial.println(n);
}

static void doStop() {
    allMotorsOff();
    stepper.stop();
    stepper.move(0);
    stepper.setMaxSpeed(STEPPER_MAX_SPEED);
    knockTargetCycles = 0;
    hopperEnabled = false;
    hopperManualUntil = 0;
    currentMode = MODE_IDLE;
    currentStep = 0;
    clearError();
    Serial.println(F("ok stop"));
}

// =====================================================
// Status / Help
// =====================================================

static const char* modeName(Mode m) {
    switch (m) {
        case MODE_IDLE:     return "idle";
        case MODE_HOMING:   return "homing";
        case MODE_STUFFING: return "stuffing";
        case MODE_STEP:     return "step";
        case MODE_ERROR:    return "error";
    }
    return "?";
}

static void printStatus() {
    bool press     = (digitalRead(PIN_INIT_PRESS)      == INIT_TRIGGERED_LEVEL);
    bool pushFront = (digitalRead(PIN_INIT_PUSH_FRONT) == INIT_TRIGGERED_LEVEL);
    bool pushRear  = (digitalRead(PIN_INIT_PUSH_REAR)  == INIT_TRIGGERED_LEVEL);
    bool magazin   = (digitalRead(PIN_MAGAZIN_SENSOR)  == MAGAZIN_TRIGGERED_LEVEL);

    Serial.print(F("status state="));    Serial.print(modeName(currentMode));
    Serial.print(F(" step="));            Serial.print(currentStep);
    Serial.print(F(" error="));           Serial.print(errorMsg[0] ? errorMsg : "");
    Serial.print(F(" press="));           Serial.print(press);
    Serial.print(F(" push_front="));      Serial.print(pushFront);
    Serial.print(F(" push_rear="));       Serial.print(pushRear);
    Serial.print(F(" magazin="));         Serial.print(magazin);
    Serial.print(F(" sol1="));            Serial.print(digitalRead(PIN_SOLENOID_1));
    Serial.print(F(" sol2="));            Serial.print(digitalRead(PIN_SOLENOID_2));
    Serial.print(F(" hopper="));          Serial.print(digitalRead(PIN_HOPPER_MOTOR));
    Serial.print(F(" hopper_enabled="));  Serial.print(hopperEnabled ? 1 : 0);
    Serial.print(F(" stepper_pos="));     Serial.println(stepper.currentPosition());
}

static void printHelp() {
    Serial.println(F("=== Stopfmaschine v0.3 ==="));
    Serial.println(F("ping | status | help"));
    Serial.println(F("params | get <k> | set <k> <v>"));
    Serial.println(F("home | stuff | step <1..11> | stop"));
    Serial.println(F("stepper <steps>"));
    Serial.println(F("press fwd|rev|stop  (PWM aus params.press_pwm)"));
    Serial.println(F("pusher fwd|rev|stop (PWM aus params.pusher_pwm)"));
    Serial.println(F("servo <0..180>"));
    Serial.println(F("solenoid 1|2 off|pulse <ms>   (Dauer-ON deaktiviert)"));
    Serial.println(F("hopper on|off|test <ms>   (on = 10s/20s Cycle)"));
    Serial.println(F("knock [<cycles>]"));
    Serial.println(F("========================="));
}

// =====================================================
// Manual-Befehle (nur im IDLE-Mode)
// =====================================================

static bool requireIdle() {
    if (currentMode == MODE_IDLE) return true;
    Serial.print(F("err busy mode=")); Serial.println(modeName(currentMode));
    return false;
}

static void cmdSolenoid(uint8_t pin, const String& action) {
    const char* name = (pin == PIN_SOLENOID_1) ? "sol1" : "sol2";
    if (action == "on") {
        // Dauer-ON ist DEAKTIVIERT. Die Heschen-Magnete sind nicht für
        // Dauerbetrieb ausgelegt (hat schon eine Sicherung gekostet). Es gibt
        // nur noch pulse/off — so kann kein Pfad (App, API, Serial) einen
        // Magneten dauerhaft halten. Pin sicherheitshalber auf LOW.
        digitalWrite(pin, LOW);
        Serial.print(F("err on_disabled ")); Serial.println(name);
    } else if (action == "off") {
        digitalWrite(pin, LOW);
        Serial.print(F("ok ")); Serial.print(name); Serial.println(F(" off"));
    } else if (action.startsWith("pulse ")) {
        unsigned long ms = action.substring(6).toInt();
        if (ms == 0 || ms > SOLENOID_PULSE_MAX_MS) {
            Serial.print(F("err pulse_ms:1..")); Serial.println(SOLENOID_PULSE_MAX_MS);
            return;
        }
        digitalWrite(pin, HIGH);
        delay(ms);   // Manual-Pulse darf blocken, ist <1 s
        digitalWrite(pin, LOW);
        Serial.print(F("ok ")); Serial.print(name);
        Serial.print(F(" pulse ")); Serial.println(ms);
    } else {
        Serial.print(F("err sol_action:")); Serial.println(action);
    }
}
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
void loop() {
    // 1) Serial einlesen
    static String buffer;
    while (Serial.available() > 0) {
        char c = (char)Serial.read();
        if (c == '\n' || c == '\r') {
            if (buffer.length() > 0) {
                handleCommand(buffer);
                buffer = "";
            }
        } else {
            buffer += c;
            if (buffer.length() > 64) buffer = "";
        }
    }

    // 2) Stepper non-blocking ticken
    stepper.run();

    // 2b) Halteström sparen: Treiber im Leerlauf stromlos schalten.
    // Nur im IDLE UND wenn keine Bewegung mehr aussteht — während einer
    // Sequenz (home/stuff/step) bleibt der Treiber bestromt, damit die
    // open-loop Trommelposition erhalten bleibt. Vor jeder Bewegung wird per
    // enableStepper() wieder aktiviert.
    if (currentMode == MODE_IDLE && stepper.distanceToGo() == 0) {
        digitalWrite(PIN_STEPPER_EN, HIGH);   // EN HIGH = Treiber/Strom aus
    }

    // 3) State-Machine (home/stuff/step) ticken
    tickStateMachine();

    // 4) Hopper-Background
    tickHopper();

    // 5) Watchdog — greift nur im IDLE
    if (!watchdogTripped &&
        currentMode == MODE_IDLE &&
        (millis() - lastCommandMs > WATCHDOG_TIMEOUT_MS) &&
        lastCommandMs > 0) {
        allMotorsOff();
        hopperEnabled = false;
        Serial.println(F("warn watchdog_timeout"));
        watchdogTripped = true;
    }
}

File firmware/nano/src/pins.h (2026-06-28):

// =====================================================
// pins.h
// Zentrale Pin-Belegung für Arduino Nano
// Stopfmaschine v0.1
// =====================================================
#pragma once

// --- A4988 (Schrittmotor / Förderschnecke) ---
constexpr uint8_t PIN_STEPPER_STEP = 2;
constexpr uint8_t PIN_STEPPER_DIR  = 3;
constexpr uint8_t PIN_STEPPER_EN   = 4;   // EN ist invertiert: LOW = aktiv

// --- L298N Standard-Modul (DC-Motoren: Presse + Pusher) ---
// Großes Modul mit Kühlkörper, Schraubklemmen und ENA/ENB.
// Drehzahl-Regelung über separate Enable-Pins (echtes PWM in beide Richtungen).
//
// WICHTIG (Timer-Konflikt): Servo.h belegt auf dem ATmega328 Timer1 und
// deaktiviert damit PWM (analogWrite) auf D9/D10. ENA/ENB MÜSSEN deshalb auf
// Timer0-PWM-Pins (D5/D6) liegen. Die IN-Pins sind reine digitale
// Richtungspins — die dürfen auf D7–D10 (kein PWM nötig).
//
//   D5  ──► L298N ENA  (PWM Timer0, Presse Drehzahl)
//   D6  ──► L298N ENB  (PWM Timer0, Pusher Drehzahl)
//   D7  ──► L298N IN1  (Presse Richtung A, digital)
//   D8  ──► L298N IN2  (Presse Richtung B, digital)
//   D9  ──► L298N IN3  (Pusher Richtung A, digital)
//   D10 ──► L298N IN4  (Pusher Richtung B, digital)
constexpr uint8_t PIN_PRESS_ENA   = 5;    // PWM (Timer0, Servo-unabhängig)
constexpr uint8_t PIN_PUSHER_ENB  = 6;    // PWM (Timer0, Servo-unabhängig)
constexpr uint8_t PIN_PRESS_IN1   = 7;    // digital
constexpr uint8_t PIN_PRESS_IN2   = 8;    // digital
constexpr uint8_t PIN_PUSHER_IN3  = 9;    // digital (Servo killt hier nur PWM)
constexpr uint8_t PIN_PUSHER_IN4  = 10;   // digital

// --- Servo Hülsen-Schieber ---
constexpr uint8_t PIN_SERVO          = 11;

// --- Hülsenmagazin-Motor (kleiner DC-Motor, 5 V, ~40 mA) ---
// Verdrahtung: Nano D12 → 1 kΩ → Gate eines kleinen N-MOSFETs (2N7000 / IRLZ44N).
// Motor zwischen 5V-Bus und Drain. Source an GND. 1N4148 als Flyback-Diode
// parallel zum Motor (Kathode an +5V). Nano-Pin direkt würde 40 mA grenzwertig
// belasten — MOSFET-Treiber ist sicherer.
// Steuerung: digital ON/OFF (D12 ist nicht PWM-fähig; Vibrationsmotor braucht
// keine Drehzahl-Regelung).
constexpr uint8_t PIN_HOPPER_MOTOR   = 12;

// --- Hubmagnet #2 (Top-Druck, Tabak-Dosierung) ---
// Verdrahtung: Nano D13 → 100 Ω → Gate eines IRLZ44N (Logic-Level-MOSFET).
// Solenoid zwischen 12V-Bus und Drain. Source an GND. 1N5819 Flyback parallel
// zum Solenoid (Kathode an +12V).
// L298N-Mini wurde verworfen: ~2,5 V Spannungsabfall + Wärme bei Halteströmen.
// MOSFET: < 20 mV Drop, kein Wärmeproblem, Solenoid sieht volle 12 V.
constexpr uint8_t PIN_SOLENOID_2     = 13;

// --- Initiatoren (induktive Näherungssensoren über Spannungsteiler) ---
// Hinweis: 12V Sensorsignal über 10kΩ + 7,5kΩ Spannungsteiler auf 5V
constexpr uint8_t PIN_INIT_PRESS      = A0;
constexpr uint8_t PIN_INIT_PUSH_FRONT = A1;
constexpr uint8_t PIN_INIT_PUSH_REAR  = A2;

// --- Tabak-Dosierung (nur Solenoide — KEIN Tabak-Servo!) ---
// Mechanismus aus Fraens' vollautomatischer Variante:
//   - 2× Heschen HS-0530B Hubmagnete pulsieren synchron (Front-Knock + Top-Druck)
//   - kein Servo dazwischen — die ursprünglich angedachte Tilt-Wand wurde durch
//     die Doppel-Solenoid-Lösung ersetzt
//   - Pro Solenoid: 1× IRLZ44N MOSFET + 1× 1N5819 Flyback-Diode
//   - Solenoid #2 siehe oben (D13), Solenoid #1 hier:
constexpr uint8_t PIN_SOLENOID_1     = A4;  // → MOSFET → Heschen HS-0530B (Front-Knock)

// A3 ist frei (Reserve — z. B. zukünftige Sensoren, I²C-Display etc.)

// --- Magazin-Lichtschranke (Trommel-Index) ---
constexpr uint8_t PIN_MAGAZIN_SENSOR = A5;  // Gabellichtschranke, direkt 5 V-Logik

// === Steuerung ist komplett remote-only (Pi → Serial → Nano). ===
// Manueller Start-Taster entfällt — kein physischer Pin reserviert.

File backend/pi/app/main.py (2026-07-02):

"""
Stopfmaschine - Pi Backend (FastAPI v0.3.0)

Spiegelt die Nano-Firmware v0.3.0 als REST + WebSocket. iOS-App spricht nur
mit dem Pi, nicht direkt mit dem Nano.

Endpoints:
    GET  /                          health
    GET  /status                    parsed MachineStatus
    GET  /params                    alle EEPROM-Parameter
    PUT  /params                    batch-update (nur gesetzte Felder)
    PUT  /params/{key}              einzelner Wert
    POST /sequence/home             Referenzfahrt
    POST /sequence/stuff            Vollsequenz
    POST /sequence/step             {"n": 1..11}
    POST /sequence/stop             Notaus
    POST /manual/stepper            {"steps": N}
    POST /manual/press              {"direction":"fwd|rev|stop"}
    POST /manual/pusher             {"direction":"fwd|rev|stop"}
    POST /manual/servo              {"angle": 0..180}
    POST /manual/solenoid/{1|2}     {"action":"off|pulse","ms":?}  (Dauer-ON deaktiviert)
    POST /manual/hopper             {"action":"on|off|test","ms":?}
    POST /manual/knock              {"cycles": ?}
    POST /system/shutdown           Pi sicher herunterfahren (stop + poweroff)
    POST /system/reboot             Pi neu starten (stop + reboot)
    POST /system/update             git pull + Abhängigkeiten + Dienst-Neustart
    POST /system/flash-nano         Nano-Firmware (firmware.hex) via avrdude flashen
    WS   /ws/status                 5 Hz Push (200 ms)

Start:
    cd backend/pi
    python -m venv .venv && source .venv/bin/activate
    pip install -r requirements.txt
    uvicorn app.main:app --host 0.0.0.0 --port 8000 --reload
"""
from __future__ import annotations

import asyncio
import logging
import os
import socket
import subprocess
import time
from contextlib import asynccontextmanager

from fastapi import BackgroundTasks, FastAPI, HTTPException, Path, WebSocket, WebSocketDisconnect
from fastapi.middleware.cors import CORSMiddleware

from .broadcaster import StatusBroadcaster
from .event_log import event_log
from .nano_client import NanoClient
from .schemas import (
    CommandResponse,
    HopperRequest,
    KnockRequest,
    MachineStatus,
    MotorRequest,
    Params,
    ServoRequest,
    SolenoidRequest,
    StepRequest,
    StepperRequest,
)
from .status_parser import parse

logger = logging.getLogger("uvicorn.error")

SERIAL_PORT = os.environ.get("STOPF_SERIAL_PORT", "/dev/ttyACM0")
SERIAL_BAUD = int(os.environ.get("STOPF_SERIAL_BAUD", "115200"))

nano = NanoClient(port=SERIAL_PORT, baud=SERIAL_BAUD)
broadcaster = StatusBroadcaster(nano, interval_ms=200)


@asynccontextmanager
async def lifespan(app: FastAPI):
    await nano.connect()
    await broadcaster.start()
    event_log.info(f"Backend gestartet (v{app.version})")
    try:
        yield
    finally:
        await broadcaster.stop()
        await nano.disconnect()


app = FastAPI(
    title="Stopfmaschine API",
    description="Steuerung der Zigarettenstopfmaschine — gespiegelt zu Nano-Firmware v0.3.0",
    version="0.3.0",
    lifespan=lifespan,
)

# CORS für iOS-Sim, lokale Tools, ggf. zukünftige PWA. Lokales Netz only.
app.add_middleware(
    CORSMiddleware,
    allow_origins=["*"],
    allow_credentials=False,
    allow_methods=["*"],
    allow_headers=["*"],
)


# -------- Helpers --------

async def _send_cmd(cmd: str) -> CommandResponse:
    reply = await nano.send(cmd)
    parsed = parse(reply)
    ok = parsed.get("_kind") in ("ok", "status", "pong", "ready")
    return CommandResponse(sent=cmd, reply=reply, ok=ok, parsed=parsed)


# -------- Internet-Erreichbarkeit (für App-Update-Gating) --------

_internet_cache = {"ok": False, "ts": 0.0}
_INTERNET_TTL = 20.0   # Sekunden — Ergebnis kurz cachen, Probe ist teuer


def _probe_internet() -> bool:
    """Blockierend: TCP zu github.com:443 (genau das, was git pull braucht)."""
    try:
        with socket.create_connection(("github.com", 443), timeout=2):
            return True
    except OSError:
        return False


async def _internet_ok() -> bool:
    now = time.time()
    if now - _internet_cache["ts"] < _INTERNET_TTL:
        return _internet_cache["ok"]
    loop = asyncio.get_event_loop()
    ok = await loop.run_in_executor(None, _probe_internet)   # Event-Loop nicht blocken
    _internet_cache["ok"] = ok
    _internet_cache["ts"] = now
    return ok


# -------- Health + Status --------

@app.get("/", summary="Health check")
async def root():
    return {
        "service": "stopfmaschine",
        "version": app.version,
        "nano_connected": nano.is_connected,
        "nano_port": nano.port,
        "internet": await _internet_ok(),
    }


@app.get("/status", response_model=MachineStatus, summary="Parsed Maschinenstatus")
async def status():
    return await nano.get_status()


# -------- Ereignis-Protokoll --------

@app.get("/events", summary="Ereignis-Protokoll (neueste zuerst)")
async def get_events():
    return event_log.list()


@app.delete("/events", response_model=CommandResponse, summary="Protokoll leeren")
async def clear_events():
    event_log.clear()
    return CommandResponse(sent="clear-events", reply="cleared", ok=True, parsed=None)


# -------- Parameter --------

@app.get("/params", summary="Alle EEPROM-Parameter")
async def get_params():
    return await nano.get_params()


@app.put("/params", response_model=CommandResponse, summary="Mehrere Parameter setzen (Batch)")
async def put_params(params: Params):
    payload = params.model_dump(exclude_unset=True)
    if not payload:
        raise HTTPException(400, "no fields to update")
    results = []
    last_reply = ""
    all_ok = True
    for k, v in payload.items():
        ok, reply = await nano.set_param(k, v)
        results.append({"key": k, "value": v, "ok": ok, "reply": reply})
        last_reply = reply
        if not ok:
            all_ok = False
    return CommandResponse(
        sent=f"batch ({len(payload)} keys)",
        reply=last_reply,
        ok=all_ok,
        parsed={"results": results},
    )


@app.put("/params/{key}", response_model=CommandResponse, summary="Einzelnen Parameter setzen")
async def put_param(key: str, value: int):
    ok, reply = await nano.set_param(key, value)
    return CommandResponse(sent=f"set {key} {value}", reply=reply, ok=ok, parsed=parse(reply))


# -------- Sequence --------

@app.post("/sequence/home", response_model=CommandResponse)
async def seq_home():
    return await _send_cmd("home")


@app.post("/sequence/stuff", response_model=CommandResponse)
async def seq_stuff():
    return await _send_cmd("stuff")


@app.post("/sequence/step", response_model=CommandResponse)
async def seq_step(req: StepRequest):
    return await _send_cmd(f"step {req.n}")


@app.post("/sequence/stop", response_model=CommandResponse, summary="Notaus")
async def seq_stop():
    return await _send_cmd("stop")


# -------- Manual --------
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

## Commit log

2026-05-01 Initialer Projekt-Stand: Firmware, Backend, CAD, Doku
    - Arduino-Nano-Firmware (Test-Stage 0.1) mit Serial-Befehlen für
    Stepper, DC-Motoren, Servo, Initiatoren und Watchdog
    - Pi-Backend (FastAPI) mit Endpoints fuer ping, status, stepper,
    servo, press, pusher, stop
    - CAD-Struktur (source, drawings, reference, stl, scad) mit DXFs
    und STLs aus dem Fraens-Engineering-Projekt
    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
    [Acryl cuttings_01.DXF, Metal parts.DXF, Metal_part_Pos_63.dxf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]
2026-05-01 fix(docs): Mermaid-Diagramme GitHub-kompatibel machen
    GitHubs Mermaid-Renderer (v11) toleriert keine runden Klammern in
    quoted Labels und ist zickig bei Emojis und manchen Unicode-Zeichen.
    - Klammern aus Node-Labels entfernt: "(...)" -> ohne Klammern
    - Emojis (Feuer-Zeichen) aus F1/F2/F3-Labels entfernt
    - Unicode-Sonderzeichen ersetzt: Groesser-Gleich -> "min.",
    Mal-Zeichen -> "Stueck", Pfeil -> "zu"
    - subgraph NANO ["Arduino Nano"] -> subgraph NANO [Arduino Nano]
    (Quotes weg; Standard-Mermaid-Syntax)
    Verifiziert via Mermaid v11 Parser (alle 3 Bloecke parsen OK).
2026-05-01 fix(motors): L298N-Mini-Modul ohne ENA/ENB unterstuetzen
    Verwendetes L298N-Modul (1,5 A je Kanal, 6-Pin-Variante) hat keinen
    ENA/ENB-Anschluss; Enable ist intern fix auf HIGH verdrahtet.
    Drehzahl-Regelung laeuft daher per PWM direkt auf den IN-Pins
    ("sign-magnitude PWM").
    Pin-Remap (PWM-faehige Pins fuer FWD-Richtung):
    D5 IN1 (PWM, Presse FWD, drehzahlgeregelt)
    D6 IN3 (PWM, Pusher FWD, drehzahlgeregelt) -- war D7
    D7 IN2 (digital, Presse REV, volle Drehzahl) -- war D6
    D8 IN4 (digital, Pusher REV, volle Drehzahl)
    D9, D10 frei (waren ENA/ENB - entfallen)
    Servo bleibt auf D11 mit Standard-Servo.h. Timer-Konflikte vermieden:
    PRESS_IN1 und PUSHER_IN3 nutzen beide Timer0 (D5/D6); S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
    [config.h, main.cpp, pins.h]
2026-05-01 feat(button): TTP223 durch mechanischen Drucktaster ersetzen
    Vorteile: robust gegen Tabakstaub und Motor-EMI, nur 2 Kabel statt 3,
    keine zusaetzliche 5V-Versorgung noetig.
    Verkabelung:
    Nano D12 ───●─── Pin 1 Taster
    │
    └── interner Pull-up (~30kOhm)
    Nano GND ──────── Pin 2 Taster
    Logik invertiert: ungedrueckt = HIGH (Pull-up), gedrueckt = LOW (gegen GND).
    Code-Aenderungen:
    - pins.h: PIN_TOUCH -> PIN_BUTTON (D12 unveraendert)
    - main.cpp: pinMode INPUT -> INPUT_PULLUP
    - main.cpp: digitalRead == HIGH -> == LOW
    - main.cpp: status-Feld touch= -> button=
    - config.h: TOUCH_DEBOUNCE_MS -> BUTTON_DEBOUNCE_MS
    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
    [config.h, main.cpp, pins.h]
2026-05-01 docs: Spannungsteiler-Dokumentation erweitert
    Praktische Hinweise ergaenzt, die bei DIY-Aufbauten haeufig fehlen
    und direkt zu kaputten Mikrocontrollern oder phantom-Triggern fuehren:
    wiring.md - § 3 Initiator-Spannungsteiler:
    - ASCII-Schaltbild mit Filter-C (47 nF parallel zu R2)
    - Hinweis auf Twisted-Pair-Verkabelung gegen Common-Mode-EMI
    - Tabelle "Was beim Spannungsteiler beachten" (Position, R-Werte,
    R-Toleranz, R-Leistung, Filter-C, Kabel, GND, Pull-up)
    - Test-Checkliste vor dem Anschluss am Nano (acht Schritte)
    - Filter-C-Tabelle mit Grenzfrequenzen und Latenzen
    - Hinweis: Widerstaende nahe Nano, nicht am Sensor (12 V auf Kabel
    ist robuster als 5 V auf Kabel)
    pinout.md - neue S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
2026-05-01 docs: Elko-Spezifikationen und Pull-up-Hinweise ergaenzt
    Ergebnisse mehrerer Diskussionen mit dem Builder eingepflegt — typische
    DIY-Fehler vermeiden:
    wiring.md:
    - A4988-Block: Elko-Spezifikationstabelle mit Kapazitaet, Spannung,
    Typ (Low ESR Pflicht!), Temperatur, Position. Plus Warnung gegen
    16 V-Elkos im 12 V-Pfad.
    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
2026-05-01 docs(fuses): Glas und Keramik gleichwertig zulassen
    Bei 12 V DC sind Glas- und Keramik-Schmelzsicherungen elektrisch
    absolut gleichwertig. Vorher war die Doku einseitig pro Glas
    formuliert ("Warum Glas, nicht keramisch?", "Glas, nicht Keramik")
    - jetzt material-neutral.
    Anlass: Builder hat Keramik-Sicherungen zur Hand, muesste Glas
    erst bestellen. Da beide elektrisch identisch sind (gleicher Wert,
    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
2026-05-10 docs(wiring): A4988 GND-Pins, WAGO Bus-Verteilung, Flyback-Dioden
    Mehrere praktische Klarstellungen aus den letzten Diskussionen:
    A4988 § 4 ergaenzt:
    - Beide GND-Pins (GND_motor + GND_logic) muessen extern an den
    Sternpunkt — Erklaerung Ground Bounce, Tabelle was bei nur einem
    GND passiert (~75 mV Verschiebung -> verlorene Steps)
    - Twisted-Pair-Empfehlung fuer Versorgungsleitungen
    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
2026-05-12 docs(cables): Litzen-Bestellliste in pinout.md ergaenzt
    Neue Sektion "Litze / Kabel (Bestellliste)" mit:
    - Querschnitt-Tabelle pro Strecke (15 Pfade) mit Strom, mm² und AWG
    - Spannungsabfall-Tabelle mit Beispielen (max 100 mV bei 5V, 500 mV bei 12V)
    - Litze vs. Massivdraht Vergleich (Empfehlung: Litze wegen Vibration)
    - Aderendhuelsen-Notwendigkeit pro Klemmentyp
    - "Wenn du nur eine Litze kaufst" -> 0,5 mm² als Universal-DIY
    - Konkretes Bestell-Paket (Reichelt-Bestellnummern, Amazon-Set, Budget)
    Wichtigste Regel: GND-Litze immer mindestens so dick wie +Leitung.
2026-05-12 docs(wiring): WAGO 10-Pol Verdrahtungsplan ergaenzt
    User hat 10-Pol-Hebelklemmen besorgt - exakt richtig fuer den Aufbau,
    GND und +12V passen je in eine Klemme ohne Daisy-Chain.
    Sektion "Bus-Verteilung praktisch" in wiring.md § 1 erweitert um:
    - 10-Pol-Variante in WAGO-Tabelle ergaenzt (mit "Optimum"-Markierung)
    - Vollstaendiger Verdrahtungsplan 2× 10-Pol-Klemme:
    * Pin-Belegung GND-Sternpunkt (10 Anschluesse: PSU-, Buck VIN-/VOUT-,
    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
2026-05-15 refactor(motors): zurueck auf ENA/ENB nach Wechsel auf grosse L298N
    User hat die grosse Standard-L298N (Kuehlkoerper, Schraubklemmen,
    ENA/ENB) bestellt - dicke Litze passt jetzt, echte Drehzahl-Regelung
    in beide Richtungen moeglich. Sign-magnitude-PWM-Workaround entfaellt.
    WICHTIG - latenter Bug im Original-Starter behoben:
    Der urspruengliche Starter hatte ENA/ENB auf D9/D10 + Servo auf D11.
    Die Standard-Servo.h belegt auf dem ATmega328 Timer1 und deaktiviert
    damit analogWrite (PWM) auf D9/D10 (offiziell dokumentiertes
    Arduino-Verhalten). ENA/ENB-PWM waere also tot gewesen.
    Loesung: ENA/ENB auf D5/D6 (Timer0-PWM, Servo-unabhaengig). IN-Pins
    sind reine digitale Richtungspins -> D7-D10 unkri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
    [config.h, main.cpp, pins.h]
2026-05-15 docs: Audit-Funde behoben (Konsistenz + veraltete Infos)
    Vollstaendiger Doku-Audit gegen die Firmware als Source-of-Truth.
    8 Funde korrigiert:
    ROT (echte Fehler / veraltet):
    1. README.md docs-Struktur: circuit-diagram.pdf + fraens-reference.pdf
    (existierten nie) entfernt, wiring.md ergaenzt (war komplett
    ungelistet trotz groesster Datei)
    2. wiring.md Servo-Elko-Tabelle: Begruendung "DC-Motor mit niedriger
    Schaltfrequenz" war Copy-Paste aus L298N-Block -> korrekt auf
    Servo-Strompulse umformuliert
    GELB (Konsistenz):
    3. README.md: nicht-existente Dateien (commands/motors/sensors/
    statemachine/api/models/db/tests/app) als "(geplant)" markiert
    statt als Ist-Zustand
    4. README.m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
2026-05-21 build/docs: CH340-Flash, Arduino IDE-Portabilitaet, Initiator-Praxis
    Sammelcommit der Aenderungen aus der Inbetriebnahme-Phase:
    BUILD/FIRMWARE:
    - platformio.ini: upload_speed = 57600 fuer CH340-Clone-Nano
    (alter Bootloader). Bei "stk500_getsync not in sync" der Standard-Fix.
    - config.h: #ifndef-Guards fuer SERIAL_BAUD und FIRMWARE_VERSION.
    Macht den Code portabel — kompiliert jetzt in PlatformIO (Build-Flags)
    UND in Arduino IDE (Fallback-Defaults). Vorher Arduino-IDE = Compile-
    Fehler "SERIAL_BAUD not declared".
    wiring.md § 3 ergaenzt:
    - Tabelle "Ersatzwerte fuer 7,5 kOhm": 6,8 kOhm (Standard), 5,6+2 kOhm
    in Reihe, 8,2 kOhm grenzwertig — mit Hinweis Reihe addiert vs Parallel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
    [config.h]
2026-05-22 firmware: Magazin-Lichtschranke in status-Output aufgenommen
    Die v0.1-Firmware hat den Magazin-Sensor (A5) bisher gelesen aber nicht
    ausgegeben. Jetzt sichtbar im status:
    status ... magazin=B magazin_raw=B ...
    - magazin = interpretierter "getriggert"-Zustand laut
    MAGAZIN_TRIGGERED_LEVEL (Default HIGH; bei opto-Modulen
    mit Pull-up ist Flagge-im-Schlitz typisch HIGH)
    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
2026-05-23 docs: Tabak-Dosierung umgestellt von Foerderschnecke auf Tilt + 2 Solenoide
    Korrektur einer grundlegenden Fehlannahme: Foerders nicht-vollautomatische
    Maschine nutzt Foerderschnecke — die vollautomatische Variante (was wir bauen)
    hat einen anderen Mechanismus, bestaetigt durch das STEP-Modell + Fraens-
    Webseite.
    NEUER MECHANISMUS (aus Fraens-STEP "Filling machine.STEP" + Webseite):
    - Tabak-Servo schwenkt Tilt-Wand vor/zurueck
    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
2026-06-02 Tabak-Dosierung auf Hubmagnete umgestellt (Heschen HS-0530B)
    - pins.h: D13 → PIN_SOL_TOP, A3 → PIN_TABAK_SERVO, A4 → PIN_SOL_FRONT;
    PIN_STATUS_LED entfernt; NEMA 17 ist jetzt Trommelantrieb
    - config.h: STEPPER_FEED_STEPS → DRUM_STEPS_PER_POS; Solenoid-Timing
    (KNOCK_CYCLES, SOL_PULSE_MS, SOL_PAUSE_MS) und Tabak-Servo-Positionen ergänzt
    - main.cpp: knock1/knock2 und tabakservo Befehle hinzugefügt;
    zweites Servo-Objekt (tabakServo) an A3; allMotorsOff() schaltet Solenoide ab
    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
2026-06-27 feat: Start-Taster entfaellt, 3 MOSFET-Aktoren (Solenoide + Hopper-Motor)
    Grosser Architektur-Schritt, mehrere Aenderungen sauber kombiniert:
    ARCHITEKTUR:
    - Steuerung jetzt 100 % remote ueber den Pi — Hardware-Start-Taster
    entfaellt komplett. Damit wird D12 frei.
    - L298N-Mini fuer Solenoide verworfen: Heschen-Halteströme ~1A bei
    2,5 V L298N-Drop = 2,5 W pro Kanal → Mini ohne Kuehlkoerper
    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
2026-06-28 fix: Tabak-Servo entfaellt — Knock laeuft nur ueber 2 Solenoide
    User-Korrektur: Es gibt im finalen Aufbau nur EINEN Servo (Huelsen-
    Schieber, D11). Die urspruenglich angedachte Tabak-Tilt-Schwenkwand
    mit eigenem Servo entfaellt — die zwei Hubmagnete schaffen die
    Dosierung alleine durch synchrones Pulsen (Schwerkraft + Impuls).
    PIN A3 wird wieder frei (Reserve).
    Firmware (v0.2.0 aktualisiert):
    - pins.h: PIN_TABAK_SERVO entfernt (A3 = Reserve)
    - config.h: TABAK_SERVO_REAR/FRONT entfernt
    - main.cpp:
    * Servo tabakServo Objekt entfernt
    * tabakServo.attach() im setup() entfernt
    * Befehl "tabak_servo <angle>" entfernt
    * runKnock(): Servo-Bewegung raus, nur noch synchrones Pulsen
    b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
    [config.h, main.cpp, pins.h]
2026-06-29 feat: Firmware v0.3, Pi-Backend v0.3, iOS-App, Pi-Setup
    Nano-Firmware v0.3.0:
    - EEPROM-Parameter-Store (params.h/cpp): 18 live-tunbare Werte mit
    Magic+CRC, self-healing Defaults, set/get/params per Serial
    - Kooperative State-Machine (idle/homing/stuffing/step/error),
    non-blocking — stop greift jederzeit
    - Sensorgefuehrte Steps mit Timeout-Watchdogs (Press-FWD, Pusher
    FWD/REV, Trommel-Home via Gabellichtschranke)
    - Knock als Sub-Loop, PWM-Drehzahl aus Params (press/pusher)
    - Background-Hopper-Cycle (10s aus / 20s an, parallel zur Sequenz)
    Pi-Backend v0.3.0 (FastAPI):
    - Alle REST-Endpoints (params/sequence/manual) + WebSocket /ws/status
    - Status-Parser, Pydantic-Schemas, Broadcaster,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
    [broadcaster.py, config.h, main.cpp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]
2026-06-30 feat(pi): Netzunabhängigkeit — Pi als WLAN-Access-Point
    - ap-mode.sh: Pi spannt eigenes WLAN auf (NetworkManager, ipv4 shared
    → DHCP+NAT automatisch, Pi = 10.42.0.1). SSID/Passwort als Args.
    - wifi-mode.sh: zurück ins Heim-WLAN. Beide SSH-sicher via systemd-run.
    - docs/pi-network.md: Umschalten, AP-immer-an, Fallback (home-sonst-AP
    über autoconnect+priority), Verifikation, Caveats.
    - App/Backend/Firmware unverändert — stopf.local + Bonjour laufen über
    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
2026-06-30 feat: sauberes Herunterfahren aus der App (Shutdown/Reboot)
    Verhindert SD-Karten-Korruption durch hartes Stromziehen.
    - Backend: POST /system/shutdown + /system/reboot. Stoppt zuerst die
    Maschine (stop an Nano), gibt HTTP-Antwort zurück, fährt dann via
    BackgroundTask herunter (sudo -n poweroff/reboot).
    - setup.sh: sudoers-Drop-in (NOPASSWD nur poweroff/reboot), mit
    visudo-Validierung vor Installation.
    - iOS: APIClient.shutdown()/reboot(), System-Sektion im Verbindungs-Tab
    mit Bestätigungsdialog + Toast.
    - docs/pi-setup.md: Abschnitt 8 (sauberes Herunterfahren + Overlay-FS),
    Troubleshooting für „Pi bootet nicht nach hartem Aus".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
    [main.py]
2026-06-30 feat(pi): flash-nano.sh — Nano vom Pi aus flashen (avrdude)
    - flash-nano.sh: stoppt Backend (gibt Serial-Port frei), erkennt Port,
    flasht .hex via avrdude (Baud 57600 für CH340, Fallback 115200),
    startet Backend wieder. avrdude wird bei Bedarf installiert.
    - docs/pi-setup.md: Abschnitt 9 — Firmware-Update-Workflow (Mac baut .hex,
    scp auf Pi, flash-nano.sh).
    Nano kann am Pi-USB bleiben; keine PlatformIO-Toolchain auf dem Pi nötig.
2026-06-30 fix(pi): Reliability — WLAN-Powersave aus + Overlay-FS/Unterspannung dokumentiert
    Behebt zwei wiederkehrende Probleme:
    - Verbindung erst nach mehreren Versuchen: WLAN-Energiesparmodus des
    Pi Zero 2 W. setup.sh schaltet ihn permanent ab (NetworkManager-Conf).
    - Pi muss nach wenigen Neustarts neu geflasht werden: SD-Korruption durch
    hartes Stromabschalten/Unterspannung. Troubleshooting verweist auf
    Overlay-FS (Abschnitt 8), vcgencmd get_throttled und gute SD-Karte.
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2026-07-01 fix(pi): Serial-Desync — params kam leer an
    send() leert jetzt vor jedem Schreiben den Input-Buffer
    (reset_input_buffer). Bisher konnte ein einmal in den Timeout gelaufener
    readline die Zuordnung Befehl↔Antwort um eins verschieben (Desync mit dem
    200-ms-Status-Broadcaster). Folge: `params` bekam eine `status`-Zeile
    zurück → _kind != "ok" → leeres Parameter-Dict, obwohl der Nano verbunden
    war und `status` sauber lief.
    [nano_client.py]
2026-07-01 fix(pi): Serial-Glitch (termios EIO) killte Broadcaster → App offline
    reset_input_buffer (aus dem vorherigen Desync-Fix) wirft bei USB-Serial-
    Aussetzern termios.error/EIO — das ist KEIN OSError und wurde daher nicht
    gefangen. Folge: jeder Broadcaster-Tick brach ab → keine WS-Frames → App
    zeigte „offline", obwohl REST lief.
    - reset_input_buffer jetzt best-effort (Fehler ignoriert).
    - except-Block breit (Exception) → termios.error löst wie jeder Serial-
    Fehler den Reconnect aus. Damit erholt sich das Backend selbst von
    USB-Glitches, statt dauerhaft keine Frames mehr zu senden.
    [nano_client.py]
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2026-07-01 feat: Ereignis-Protokoll (Fehler nachvollziehen aus der App)
    - Backend: event_log.py (In-Memory-Ringpuffer, 200 Events, wichtige Events
    zusätzlich ins journald). Broadcaster protokolliert Übergänge: Nano
    verbunden/verloren, Zustandswechsel, Fehler (mit Schritt), Ablauf
    abgebrochen (Hinweis auf Nano-Reset). System-Aktionen (Update/Flash/
    Shutdown) werden geloggt. GET /events, DELETE /events.
    - iOS: EventItem-Model, APIClient.events()/clearEvents(), EventLogView
    (farbcodiert, Zeitstempel, Refresh/Leeren), Link „Fehlerprotokoll" im
    Verbindungs-Tab.
    Erfasst Fehler auch wenn die App nicht verbunden war (Broadcaster läuft
    unabhängig). In-Memory → überlebt keinen Backend-Neus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
    [broadcaster.py, event_log.py, main.py]
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
